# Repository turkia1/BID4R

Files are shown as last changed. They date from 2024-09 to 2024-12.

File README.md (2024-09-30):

# BID4R

# Welcome to the BID4R Rover Model Senior Project

## Overview
The **BID4R Rover Model** is a project designed to develop an efficient power distribution and wireless charging system for a small swarm robot used in the Biologically Inspired Resilient Systems Test Arena (BIRSTA). The current system uses AA batteries, which only provide about 15 minutes of operational time, limiting the research capabilities of the system.

Our project focuses on upgrading one of the 50 swarm rovers to:
- Use **LiPo batteries** to extend operational time to 60 minutes.
- Implement a **wireless charging station** to eliminate manual recharging.
- **Optimize** the rover's structure and design for improved performance and safety.

This proof-of-concept project serves as the foundation for future upgrades across the entire swarm.

## Key Features
- **Power Distribution System**: Upgrading the current system to a **3000 mAh LiPo battery**.
- **Wireless Charging Protocol**: Implementing a **Qi wireless charging station** to allow for easy, cable-free recharging.
- **Rover Design Enhancements**: Reducing the rover structure from four tiers to three tiers for a simpler and more compact design.
- **3D-Printed Battery Mount**: A custom-designed mount that ensures stability and protection for the battery and charging components.
- **Battery Monitoring Algorithm**: Implementing software to track battery life, temperature, and optimize charging times to extend battery longevity.

## Stakeholders
- **Primary Stakeholders**: Dr. Watson and the Biologically-Inspired Design for Resilience Lab.
- **Secondary Stakeholders**: Research teams working on robotic swarms and engineers interested in sustainable power systems for small-scale robots.

## Project Goals
- Develop and test the power distribution system using LiPo batteries.
- Implement wireless charging on the rover and validate performance.
- Showcase a continuous operation of 60 minutes using wireless charging.

## Out of Scope
- Modifications to the remaining 49 rovers in the swarm.
- Autonomous navigation to charging stations.

## Repository Contents
- **Documentation**: All necessary documents, reports, and designs related to the BID4R rover upgrade.
- **Code**: Source code for battery monitoring, power distribution, and wireless charging protocols.
- **Designs**: 3D models for the battery mount and structural modifications of the rover.

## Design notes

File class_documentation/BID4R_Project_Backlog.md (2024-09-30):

# BID4R Project Backlog

## Sprint 1 (Sep 17 – Sep 26) - Done
**Focus:** Project setup and planning.

### Tasks Completed:
1. **Project Proposal (Team):** Done.
2. **Initial Product Backlog (Team):** Done.
3. **Team and component research strategy set (Team):** Done.

---

## Sprint 2 (Oct 1 – Oct 10)- **In Progress**
**Focus:** Research and component verification.

### Tasks:
1. **Research existing and alternative components (Mohammed):** In Progress  
  Verify if the components chosen (PowerBoost, proximity sensors, etc.) are suitable and if new ones are needed.
2. **Perform calculations (Team):** In Progress    
   Conduct power-flow calculations to check system efficiency.
3. **Design initial 3D charging station structure (Turki):**  In Progress  
   Ensure it aligns with the robot’s dimensions and has room for the cooling mechanism.
4. **Research LiPo battery safety and regulations (Belal):**  In Progress  
   Ensure the LiPo battery is compliant with safety standards and meets project requirements.

---

## Sprint 3 (Oct 15 – Oct 24)- **To Do**
**Focus:** Design finalization and algorithm development.

### Tasks:
1. **Finalize charging station design (Turki):**  To Do  
   Finalize the design of the charging station, ensuring it aligns well with the robot and cooling mechanism.
2. **Write distributed power management algorithm (Mohammed-Belal):**  To Do  
   Ensure the algorithm includes power safety protocols.
3. **Develop wiring diagram (Team):**  To Do  
   Create the wiring diagram for the robot, showing how components will be connected (PowerBoost, batteries, proximity sensors).
4. **Review and approve safety protocol (Team):**  To Do  
   Ensure the safety protocol covers all risks and is ready for testing.
5. **Prepare for component integration (Team):**  To Do  
   Gather all necessary components and start preparing for physical integration into the robot system.

---

## Sprint 4 (Oct 29 – Nov 7)- **To Do**
**Focus:** Component integration and initial testing.

### Tasks:
1. **Integrate PowerBoost, proximity sensors, and batteries (Team):**  To Do  
   Wire and physically install the key components (PowerBoost, sensors, batteries).
2. **Install wireless power transmitter and receiver (Team):**  To Do  
   Complete the integration of the wireless charging system.
3. **Test algorithm in a simulated environment (Team):**  To Do  
   Test the power management algorithm on the software side before full system integration.
4. **Test cooling mechanism prototype (Team):**  To Do  
   Ensure the charging station cooling mechanism works effectively.

---

## Sprint 5 (Nov 12 – Nov 21)- **To Do**
**Focus:** Full system testing and optimization.

### Tasks:
1. **Test full power system with wireless charging (Team):**  To Do  
   Run tests on the fully integrated power system to ensure it functions properly.
2. **Iterate on safety protocol (Team):**  To Do  
   Adjust the safety protocol based on test results, especially for overheating or charging errors.
3. **Test proximity sensor performance (Team):**  To Do  
   Ensure that the proximity sensors are working effectively with the robot’s control system.
4. **Implement charging station cooling mechanism (Team):**  To Do  
   Ensure cooling efficiency during the robot’s charging cycles.
5. **Reduce layers in power system design (Team):**  To Do  
   Optimize the design by reducing complexity in the power system if needed.
6. **Prepare and submit presentation poster (Team):** To Do   
   Start drafting the poster for the final project presentation.

---

## Sprint 6 (Nov 26 – Dec 5)- **To Do**
**Focus:** Final preparations and presentations.

### Tasks:
1. **Record 3-minute project video (Team):**  To Do  
   Create the video explaining the project and demonstrating the robot in action.
2. **Prepare final presentation (Team):**  To Do  
   Finalize the project presentation, including results, test data, and the overall project narrative.
3. **Test robot under real conditions (Team):**  To Do  
   Conduct a final test of the robot in an environment similar to its intended use case.
4. **Finalize all documentation (Team):**  To Do  
   Make sure that wiring diagrams, safety protocols, and testing data are fully documented and ready for submission.

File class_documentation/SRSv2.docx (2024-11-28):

BID4R

System Requirements Specification

Version <1.1>

27/11/2024

# Document Control

## Distribution List

The following list of people will receive a copy of this document every time a new version of this document becomes available:

Teaching assistants:

Luke Newcomb

Customer(s):

Dr.Bryan Watson

Project team members:

Turki Alturki

Belal Abed

Mohammed Alasmari

## Change Summary

The following table details changes made between versions of this document:

Version | Date | Modifier | Description
1.0 | 23/10/2024 | Turki Alturki | Introduction
1.0 | 24/10/2024 | Mohammed Alasmari | General Discerption
1.0 | 24/10/2024 | Belal Abed | External Interface Requirements
1.0 | 25/10/2024 | Turki Alturki | Behavioral Requirements
1.0 | 25/10/2024 | Mohammed Alasmari | Non- Behavioral Requirements
1.0 | 25/10/2024 | Belal Abed | Other Requirements
1.0 | 27/10/2024 | Belal, Mohammed | Analysis Models
1.0 | 29/10/2024 | Turki | To be determined list
1.1 | 27/11/2024 | Turki, Belal and Mohammed | Revision of requirements based on feedback

Table of Contents

# 1. Introduction

## Purpose and Scope

The purpose of this System Requirements Specification (SRS) is to detail the system requirements for the BID4R Project, a biologically-inspired resilient rover system designed to replace AA battery-powered rovers with LiPo battery-powered rovers. The BID4R Project focuses on upgrading power systems for autonomous robots in the Biologically-Inspired Resilient Systems Test Arena (BIRSTA), with the goal of extending operational time and introducing wireless charging functionality. Identified through needs analysis, the customer’s primary issue is the limited battery life of current rovers, which necessitates frequent manual recharging and maintenance. This new system addresses that challenge by incorporating LiPo batteries and a wireless Qi charging mechanism, enabling longer operational time and autonomous charging upon manual placement in the station. Applied to a swarm of 50 rovers, the system enhances power management, wireless charging, and control capabilities. Its top-level benefits include improved autonomy, reduced maintenance, and more efficient energy management, achieved through safe battery use managed by a Battery Management System (BMS) and optimized operational efficiency with wireless charging.

## Intended Audience and Reading Suggestions

This document is intended for several types of readers involved in or evaluating the BID4R project:

- Developers responsible for designing and implementing the system.
- Project Manager who oversees project milestones and ensures that all requirements are met.
- Customer who will review the system requirements to assess alignment with project goals.
- Professors and Teaching Assistants who will evaluate and grade the document for technical accuracy and completeness.

### Reading suggestions

- Non-Technical Readers: Focus on the Introduction and General Description sections for a high-level understanding of the project and its goals.
- Developers: Concentrate on the External Interface Requirements and Behavioral Requirements sections for design and implementation guidance.
- Project Manager: Review all sections to ensure milestones are addressed and requirements are met.
- Professors and Teaching Assistants: Examine all sections to evaluate the document's technical accuracy, organization, and alignment with project requirements.

## Document Conventions

The following standards and typographical conventions are followed in this SRS to ensure consistency and clarity:

- Hierarchical Structure: All headings follow a hierarchical numbering system, with primary headings numbered as 1, 2, 3, etc., and subheadings as 1.1, 1.2, etc., to indicate document structure.
- Fonts and Styles: Body text is in 12-point Times New Roman, while headings are bolded for clear visual separation. Terms needing emphasis are italicized, while system names and technical terms are capitalized for clarity.
- Requirement Numbering: Each requirement is labeled with a unique identifier, such as " [Req 1]”," " [Req 2]," and so on, for easy reference and traceability.
- Priority Inheritance: Priorities for higher-level requirements are inherited by lower-level requirements unless otherwise specified.

These conventions are intended to enhance readability and provide a structured approach to navigating the document.

## Project References

This section lists key references and deliverables produced to date, which provide insight into system design choices, power calculations, and safety mechanisms related to LiPo battery management. All documents are accessible on the project’s GitHub repository, with version control details included for reference.

- Project Proposal, BID4R
  - Authors: BID4R Team
  - Date: 2024
  - Description: An overview of project goals, requirements, and initial design considerations for the BID4R system.
  - GitHub Location: https://github.com/turkia1/BID4R/blob/fc681bb0e57aabb8ba3e043f27d15630247c62c0/project_proposal/Project%20Proposal%20.pdf
- Components Analysis and Suitability for BID4R Project
  - Author: Mohammed Alasmari
  - Date: October 2024
  - Description: Analysis of key components required for the BID4R system, including suitability evaluations and performance considerations.
  - GitHub Location: https://github.com/turkia1/BID4R/blob/fc681bb0e57aabb8ba3e043f27d15630247c62c0/Sprint2/Components%20Analysis%20and%20Suitability%20for%20BID4R%20Project.pdf
- LiPo Battery Safety and Wireless Charging Mechanism: A Comprehensive Guide
  - Author: Belal Abed
  - Date: October 2024
  - Description: Guidelines on LiPo battery safety standards and implementation of Qi wireless charging, focusing on safety protocols and regulatory compliance.
  - GitHub Location: https://github.com/turkia1/BID4R/blob/fc681bb0e57aabb8ba3e043f27d15630247c62c0/Sprint2/LiPo_regulation.PDF
- Final Power Calculations for BID4R
  - Authors: Mohammed Alasmari and Belal Abed
  - Date: October 2024
  - Description: Comprehensive power calculations for the BID4R system under various operating conditions, including normal and stall power requirements.
  - GitHub Location: https://github.com/turkia1/BID4R/blob/fc681bb0e57aabb8ba3e043f27d15630247c62c0/Sprint2/FinalCalculation.Component.pdf
- Wiring Documentation for BID4R
  - Author: Turki Alturki
  - Date: October 2024
  - Description: Detailed wiring documentation outlining component connections, safety protocols, and wiring schematics for BID4R.
  - GitHub Location: https://github.com/turkia1/BID4R/tree/fc681bb0e57aabb8ba3e043f27d15630247c62c0/Sprint3/Wiring
- Charging Station Documentation
  - Author: Turki Alturki
  - Date: October 2024
  - Description: Technical documentation on the design and operation of the wireless Qi charging station, including alignment and power specifications.
  - GitHub Location: https://github.com/turkia1/BID4R/tree/fc681bb0e57aabb8ba3e043f27d15630247c62c0/Sprint2/Charging_Station

## Definitions, Acronyms, and Abbreviations

This section provides a glossary of terms and acronyms used in this document.

### Definitions

Term | Definition
LiPo Battery | A type of rechargeable battery widely used for high-energy density applications.
BMS | Battery Management System, responsible for protecting batteries from overcharge, over-discharge, and short circuits.
Qi Charging | A wireless power transfer standard used for charging the rover’s battery.
Arduino Nano | The microcontroller used to manage power and motor control in the system.

### Acronyms

Term | Definition
BMS | Battery Management System
SRS | System Requirements Specification
Qi | Wireless charging technology
BID4R | Biologically-Inspired Design for Resilience

### Abbreviations

Term | Definition
e.g. | For example
V | Voltage
A | Amperes
W | Watts

# 2. General Description

## Product Perspective

The BID4R Project is a subsystem designed to improve the autonomy and operational efficiency of rovers used in the Biologically-Inspired Resilient Systems Test Arena (BIRSTA). Currently, BIRSTA's rovers rely on AA batteries, which require frequent manual replacements and limit runtime. This project aims to replace the AA batteries with a LiPo battery and integrate a Qi wireless charging system to allow convenient, operator-assisted charging.

This power upgrade enhances BIRSTA’s ability to conduct continuous testing by reducing downtime due to manual battery changes. The BID4R system consists of four main components:

1. LiPo Battery: Replaces the original AA battery pack, providing higher capacity and improved power efficiency.
2. Qi Wireless Charging Station: Enables contactless charging of the rover by an operator who manually aligns the rover on the charging pad.
3. Battery Management System (BMS): Monitors battery voltage, prevents overcharging and over-discharging, and ensures safe operation.
4. Arduino Nano-based Control System: Manages communication between the Qi charging module, LED indicators, and the BMS, providing power status updates to the operator.

Figure 1: BID4R Concept of operation illustrates the key components and connections within the system for power, charging, and control.

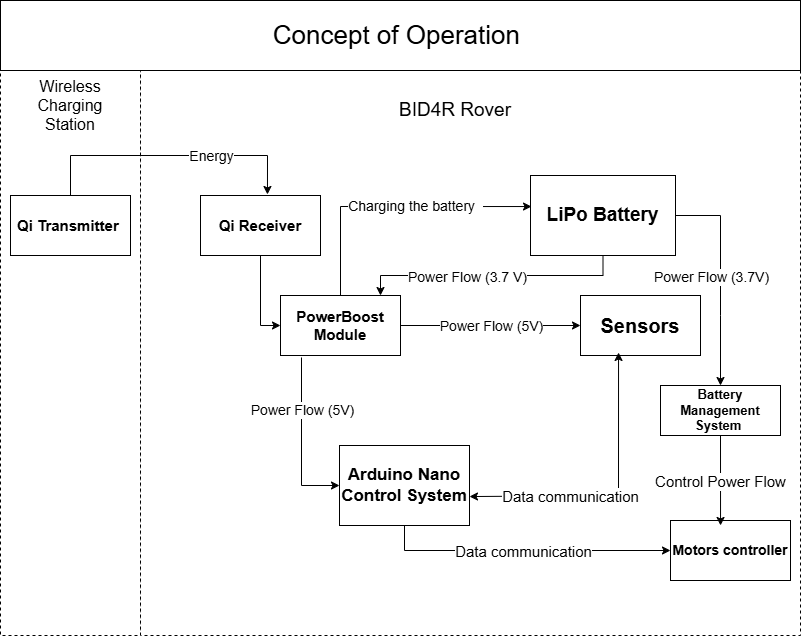
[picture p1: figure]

## Product Features

The BID4R system introduces specific power management features designed to improve battery efficiency, provide safe charging, and enable operational monitoring by the user. Key features include:

- Power Management:
  - Operator-Assisted Wireless Charging: The system uses Qi wireless technology to enable contactless charging. When the battery is low, an operator places the rover on the charging station, which detects the connection and initiates charging.
  - Battery Management System (BMS): The BMS monitors the LiPo battery, preventing overcharging and over-discharging, which ensures safe battery operation and prolongs battery life.
  - Power Monitoring: Real-time monitoring of battery voltage and temperature, displayed via an LED indicator, helps operators assess the rover’s power status.
- System Control:
  - LED Indicators for Battery Status: An LED indicator provides real-time feedback on the battery’s charge status, showing low, charging, and fully charged states, allowing operators to manage charging effectively.
  - Arduino-Controlled Charging Initiation: The system includes an Arduino Nano microcontroller to handle battery status data, control the LED indicator, and communicate with the charging station.

## User Classes and Characteristics

This system is used by the following user groups:

- Primary User: BIRSTA Staff (System Operators)
  - Function: The primary users are BIRSTA engineers or technical staff who operate and monitor the BID4R rover within the test arena.
  - Use: BIRSTA staff will place the rover on the charging station when the LED indicates low battery, monitor the LED status during charging, and remove the rover once fully charged.
  - Privileges: Full access to physical interactions with the system but no access to configurations or code adjustments.
  - Technical Expertise: Moderate; users need to understand LED indicators and basic power system handling but are not required to configure or troubleshoot the system beyond aligning the rover on the charging station.
- Secondary Users: Students (Project Developers)
  - Function: Students are responsible for developing, testing, and integrating the wireless charging station and LiPo battery upgrade, ensuring that the system operates safely and meets performance standards.
  - Use: Configure and test the Qi wireless charging system and BMS functionality.
  - Privileges: Full access to system setup and configuration but restricted to power management components.
  - Technical Expertise: Moderate-to-high; students are expected to understand LiPo battery management, wireless charging setup, and basic troubleshooting for integration.

### Actors

- BIRSTA Staff (Operators): Responsible for the day-to-day operation of the BID4R system, primarily focused on managing power levels through charging.
  - Responsibilities:
    - Observe LED indicators to monitor battery levels.
    - Place the rover on the charging station when necessary and remove it once fully charged.
- Students (Project Developers): Responsible for implementing and maintaining the charging system and battery management components.
  - Responsibilities:
    - Configure and test the Qi charging system and LiPo battery setup.
    - Monitor system safety compliance and handle troubleshooting as needed.

### Use Cases

- Figure 2: UC1: Operator-Assisted Charging

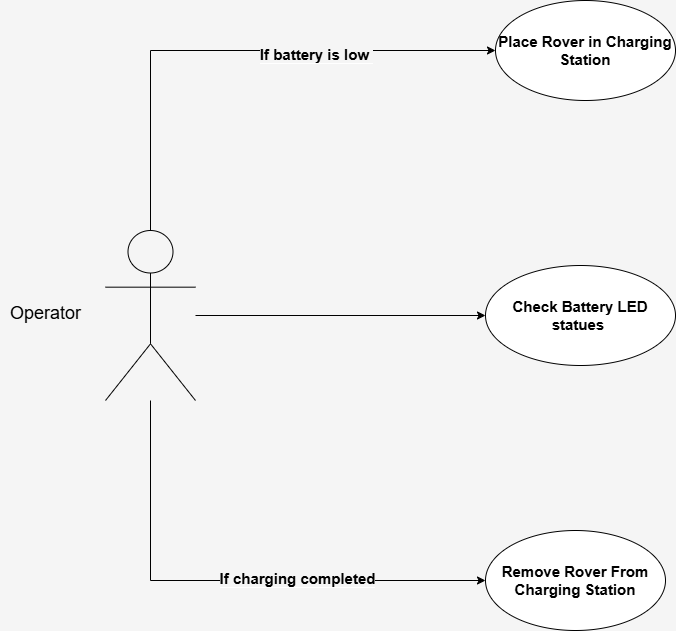
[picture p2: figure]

  - Actors: BIRSTA Staff (Operators)
  - Description: When the battery is low, the operator places the rover on the charging station, where the system automatically initiates charging.
  - Precondition: The battery level is low.
  - Postcondition: Charging begins, and the system logs the session.
  - Alternative Scenario: If alignment is incorrect, the LED remains in a low-battery state, signaling the need for realignment.
- Figure 3: UC2: Create Charging Station System

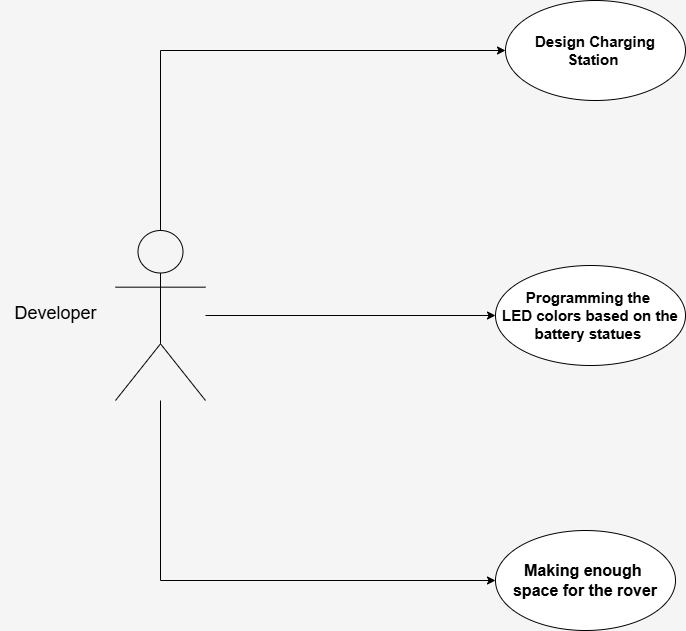
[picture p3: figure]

  - Actors: Students (Project Developers)
  - Description: The Developer designs a reliable charging station, programs LED indicators for battery status (Red, Yellow, Green, and Solid Blue), and ensures sufficient space for easy docking, removal, and maintenance of the rover.
  - Precondition: All required components (charging station, LED indicators, and rover chassis) are available, and the design specifications are approved.
  - Postcondition: The charging station is fully functional, LED indicators display the correct battery status, and the rover can dock, charge, and be removed easily for operation and maintenance.

### Scenarios

This section presents scenarios for each use case described above.

Scenario 1: Initiating Charging

- Description: When the rover’s LiPo battery is low, students monitor the LED indicator and manually place the rover on the Qi wireless charging station to initiate charging.
- Actors: Operators
- Precondition: The rover’s battery level is low, as indicated by the LED.
- Trigger: The operator observes the LED indicator showing a low battery level.
- Steps:
  1. The operator checks the LED indicator to confirm the low battery.
  2. The operator ensures the charging station is clear and ready for alignment.
  3. The operator carefully places the rover on the Qi charging station, aligning it for effective power transfer.
  4. The LED indicator changes to indicate charging, confirming proper alignment.
  5. The operator observes the LED briefly to confirm charging stability.
- Result: The rover is charging, as indicated by the LED status light.
- Alternative Path:
  6. Step 3.1: If the rover is misaligned and charging does not start, the LED remains in its low-battery state. The student repositions the rover until charging initiates.

Scenario 2: Removing the Rover After Full Charge

- Description: Once the rover’s LiPo battery is fully charged, the student observes the LED indicator and removes the rover from the charging station for deployment within BIRSTA.
- Actors: Operators
- Precondition: The rover’s battery is fully charged, indicated by the LED.
- Trigger: The operator observes the LED indicator showing a full charge.
- Steps:
  1. The operator verifies the LED to confirm the full charge status.
  2. The operator approaches the charging station to remove the rover.
  3. The operator carefully lifts the rover off the charging station.
  4. The operator inspects the LED indicator briefly to ensure it remains in the full charge state.
  5. The rover is now ready for BIRSTA deployment.
- Result: The rover is fully charged, removed from the charging station, and available for further use.
- Alternative Path:
  6. Step 3.1: If the LED flashes unexpectedly after removal, the Operator checks the charging station for alignment or functionality issues before proceeding.

## General Constraints

- Code Accessibility: The development team will not have access to the full codebase of the rover, as it is part of an unpublished project and cannot be shared with the team due to confidentiality restrictions. The team will therefore focus on developing code specifically for the battery management system (BMS) algorithm, ensuring independent functionality within the rover’s existing power system.
- Component Selection: To maintain budgetary efficiency, the team will prioritize cost-effective components that meet performance requirements, aiming to reduce overall project costs without sacrificing quality or essential functionality.
- System Modifications: The development team is constrained to avoid modifying the existing rover system to ensure it remains compatible with the customer's current operational use. This ensures the rover’s functionality and user interface remain unchanged for the customer.
- Parts Compatibility: The team will work within the constraints of using components that are already available to the customer whenever possible, ensuring compatibility and minimizing the need for introducing new, unfamiliar parts.

## Operating Environment

- The BID4R system will operate in a controlled laboratory environment within the Biologically-Inspired Resilient Systems Test Arena (BIRSTA) lab. Key environmental requirements include:
- Temperature Range: The system is designed to operate at ambient temperatures between 18°C and 27°C (64°F to 80°F). This range helps prevent temperature-induced issues such as increased viscosity in adhesives and potential component stress, maintaining stability for all electronic parts.
- Humidity: The lab environment maintains a humidity range between 30% and 70%, with a preferred range of 45-60%. These levels reduce the risk of electrostatic discharge (ESD) and prevent moisture damage to sensitive electronic components.
- Hardware Platform: The rovers are managed by an Arduino Nano microcontroller, and the Qi wireless charging station utilizes a PowerBoost 1000C module for reliable energy delivery.
- Software Requirements: The control software operates on the Arduino Nano(C++), handling communications with integrated sensors, motors, and the Battery Management System (BMS) to support system functions.

## User Documentation

The following user documentation will be provided with the BID4R system:

- Charging Station Design Documentation: Detailed design and setup instructions for the Qi wireless charging station, including component specifications and configuration guidelines to ensure proper alignment and functionality.
- Wiring Diagram: A visual guide detailing the connections between all system components, including the battery, sensors, motor drivers, and control modules, offering a reference for accurate assembly and troubleshooting.
- Components and Power Consumption Calculation Documentation: Documentation outlining the system's power requirements and consumption calculations to help users monitor and optimize energy use within safe operating limits.
- LiPo Battery Safety Regulation: Comprehensive guidelines on the safe handling, usage, and maintenance of LiPo batteries, including storage recommendations, charging protocols, and precautions to avoid overcharging or overheating.

All documentation will be provided in PDF format, formatted for clarity and ease of use, and will include annotated diagrams and visual aids where relevant to support user comprehension.

## Assumptions and Dependencies

The following assumptions and dependencies affect the requirements outlined in this SRS:

- Arduino Code Accessibility: It is assumed that the source code for controlling the Arduino Nano 33 IoT will be accessible under supervision to the development team to facilitate integration and testing of the battery management system (BMS).
- Component Provision: The organization will supply all essential components, including the Battery Management System (BMS), Qi chargers, and LiPo batteries. These components are expected to be compatible with the BID4R system and aligned with the project’s cost-efficiency goals.
- Testing Infrastructure: The system will be tested and integrated within the existing BIRSTA robotics infrastructure, assuming compatibility with current robotics protocols, interfaces, and communication systems.
- Environment Control: The system is designed for a controlled lab environment with stable temperature and humidity levels maintained within recommended ranges, supporting the safe and efficient operation of system components.
- Existing Code Functionality: It is assumed that the original rover codebase, aside from the battery management system, operates as intended with no major functional issues.
- System Integrity: It is assumed that all other aspects of the robot’s hardware and software are functioning correctly, and any issues encountered during development are limited to the scope of the team’s work (upgrading the AA battery to LiPo battery).

# 3. External Interface Requirements

## User Interfaces

- [Req 1] The system shall indicate system battery status through an RGB LED.

## Hardware Interfaces

- [Req 2] The motor driver shall be connected to the Arduino for PWM control of motor speed and direction.
- [Req 3] The system shall use an Arduino Nano microcontroller for processing and control.
- [Req 4] The proximity sensor shall be calibrated after installation to ensure accurate readings and proper communication with the Arduino.
- [Req 5] The Pixy2 shall be calibrated after installation to ensure accurate readings and proper communication with the Arduino.
- [Req 6] The system shall include one temperature sensor, positioned near the LiPo battery, to monitor its temperature during charging.
- [Req 7] The PowerBoost 1000C shall provide power for the Pixy2 camera, ensuring it operates within the combined system power limit of 1A.
- [Req 8] The PowerBoost 1000C shall provide power for the VCNL4010 proximity sensor, ensuring it operates within the combined system power limit of 1A.
- [Req 9] The PowerBoost 1000C shall provide power for the APA106 LEDs, ensuring they operate within the combined system power limit of 1A.
- [Req 10] The PowerBoost 1000C shall provide power for the Arduino Nano 33 IoT, ensuring it operates within the combined system power limit of 1A.
- [Req 11] The PowerBoost 1000C shall provide power for any additional 5V components, ensuring the total system power consumption does not exceed 1A.
- [Req 12] The PowerBoost 1000C shall receive 3.7V input from the LiPo battery and provide a stable 5V output for connected components.
- [Req 13] The motor shall be directly connected to the battery through a BMS for protection.
- [Req 14] The BMS protection module shall be installed between the LiPo battery and the load to manage safe charging and discharging.

## Software Interfaces

- [Req 15] All components shall be compatible with Arduino programming standards.
- [Req 16] The software shall monitor battery health, alerting on issues such as temperature or swelling.
- [Req 17] Software logic shall control charging based on feedback from the battery sensors.
- [Req 18] Software logic shall monitor feedback from the battery sensors and control the motors, ensuring they stop operation if dangerous conditions are detected.

# 4. Behavioral Requirements

## Modes

[Req 19] The system shall provide LED indicators for charging status, showing states such as charging, full, and standby.

[Req 20] The system shall have two modes

- Charging Mode
- [Req 21] The system shall flash the indicator LED green when the battery is above 60% charge and the system is in charging mode.
- [Req 22] The system shall flash the indicator LED yellow when the battery is between 30% and 60% charge and the system is in charging mode.
- [Req 23] The system shall flash the indicator LED red when the battery is below 30% charge and the system is in charging mode.
- [Req 24] The system shall display a solid blue indicator LED when the battery is above 95% to indicate “Charging Complete” in charging mode.
- Operation Mode
- [Req 25] The system shall display a green indicator LED when the battery is above 60% charge and the system is in operation mode.
- [Req 26] The system shall display a yellow indicator LED when the battery is between 30% and 60% charge and the system is in operation mode.
- [Req 27] The system shall display a red indicator LED when the battery is below 30% charge and the system is in operation mode.

## Related Real-world Objects

- [Req 28] The system shall maintain the battery temperature below 45°C during normal operation.
- [Req 29] The system shall alert the operator by turning the LED indicator orange if the battery temperature exceeds 45°C.
- [Req 30] The system shall monitor the battery temperature in real-time to ensure it remains within safe operating limits (below 45°C).
- [Req 31] The Arduino shall automatically cut power if the battery temperature reaches unsafe levels.
- [Req 32] The charging station shall allow manual activation by the operator of the cooling fan.
- [Req 33] The charging station shall allow manual deactivation by the operator of the cooling fan.

## Stimulus

- [Req 34] LED indicators shall change states according to battery level.
- [Req 35] Wireless charging shall commence automatically once the robot is aligned with the transmitter.
- [Req 36] The Arduino shall automatically cut power if the battery temperature reaches unsafe levels exceeding 45°C.
- [Req 37] The system shall resume charging automatically when temperature falls below 35°C if previously halted due to overheating.
- [Req 38] The system shall disable motors while charging.
- [Req 39] The system shall disable the Pixy2 camera while charging.
- [Req 40] The system shall disable the proximity sensor while charging.

## Functional

- [Req 41] The system shall stop charging when the battery voltage reaches or exceeds 4.2V automatically through PowerBoost 1000C.
- [Req 42] The system shall permit charging only when the battery voltage is below 4.2V.
- [Req 43] The system shall define a thermal cutoff as a battery temperature greater than 45°C.
- [Req 44] The system shall indicate a thermal cutoff by flashing the RGB LED orange.
- [Req 45] The system shall define non-essential components as the Pixy2 camera, motor controller, and proximity sensor.
- [Req 46] The system shall automatically stop the Pixy2 camera when the battery voltage is 3.3V or below.
- [Req 47] The system shall automatically stop the motor controller when the battery voltage is 3.3V or below.
- [Req 48] The system shall automatically stop the proximity sensor when the battery voltage is 3.3V or below.

# 5. Non-behavioral Requirements

## Performance Requirements

- [Req 49] The system shall support wireless charging via a Qi-compatible charging station.
- [Req 50] The rover shall use a LiPo battery for primary power.
- [Req 51] The BMS shall prevent battery overcharge.
- [Req 52] The BMS shall prevent battery over-discharge.
- [Req 53] Under normal operation, the LiPo battery shall provide a minimum runtime of one hour.
- [Req 54] The Qi transmitter shall maintain a stable position on the charging station base to ensure consistent power transfer.
- [Req 55] The charging station shall ensure efficient power transfer throughout the charging process without interruptions.
- [Req 56] The system shall consume no more than 13.05W at peak usage.
- [Req 57] The Qi receiver and transmitter shall be aligned within ±3 mm to optimize charging efficiency and prevent power loss.
- [Req 58] The charging station shall incorporate a rising edge and block system to ensure precise docking alignment.
- [Req 59] The LiPo battery shall have a capacity of at least 3000 mAh.
- [Req 60] The motors shall draw 2.22W during normal operation (3.7V at 300mA per motor).
- [Req 61] The motors shall draw 11.1W under stall conditions (3.7V at 1.5A per motor).
- [Req 62] Under normal operating conditions, the LiPo battery shall provide a runtime of approximately 2.66 hours.
- [Req 63] Under stall conditions, the LiPo battery shall provide a runtime of approximately 51 minutes.
- [Req 64] The total power consumption during normal operation, including motors and PowerBoost-powered components, shall not exceed 4.17W.
- [Req 65] The total power consumption during motor stall conditions shall not exceed 13.05W.
- [Req 66] The Qi wireless charging transmitter shall provide 5W output to the Qi receiver with an efficiency of 80%.
- [Req 67] The Qi charging system shall fully recharge the LiPo battery within approximately 2.78 hours.
- [Req 68] The BMS shall not consume significant power (2.22W) during normal operation, functioning as a passive protection component.
- [Req 69] The system shall be able to provide sufficient power for different components on the robot.

## Safety Requirements

- [Req 70] The system shall monitor battery temperature using a DS18B20 temperature sensor.
- [Req 71] All wiring shall be neatly organized and securely fastened to prevent interference with the robot's movement and docking.
- [Req 72] The BMS shall protect the health of the battery by preventing over-discharge.
- [Req 73] The thermal cutoff shall disconnect charging if the temperature exceeds 113°F (45°C).
- [Req 74] All electrical connections shall be insulated to prevent accidental short circuits or interference.
- [Req 75] The system shall include a BMS for parts connected directly to the battery.

## Qualitative Requirements

### Security

- [Req 76] Access to the code for the battery management system (BMS) shall be restricted to authorized team members only, ensuring secure control over system operations and modifications.

### Maintainability

- [Req 77] The BMS code shall be modular to allow for future updates and improvements without affecting unrelated system components, supporting efficient system maintenance and upgrades

## Design and Implementation Constraints

- [Req 78] The robot chassis shall securely mount the Qi receiver, providing enough space and accessibility for wiring and maintenance.
- [Req 79] The robot chassis shall securely mount all components, providing enough space and accessibility for wiring and maintenance.
- [Req 80] The Arduino Nano 33 IoT shall be positioned to allow easy access to all sensor and power connections
- [Req 81] The PowerBoost 1000C shall be positioned to allow airflow for cooling, ensuring stable operation under continuous load.
- [Req 82] The proximity sensor shall be placed at the front of the robot for optimal obstacle detection.
- [Req 83] The APA106 LEDs shall be positioned to remain visible to the operator, providing clear feedback on system status.
- [Req 84] The Qi receiver shall be positioned on the bottom surface of the robot for direct alignment with the transmitter on the charging station.
- [Req 85] Wires shall not interfere with the robot during docking.
- [Req 86] The LiPo battery shall be securely housed to prevent movement, impact, or damage during operation.
- [Req 87] All components shall be fastened securely to avoid damage or disconnection from vibrations or sudden movements.
- [Req 88] The charging station shall be designed for easy assembly and disassembly to facilitate maintenance.
- [Req 89] The design shall accommodate the BID4R robot configuration, which includes two wheels and a middle stabilizer.
- [Req 90] The Qi transmitter shall be positioned at the front of the charging station to align with the BID4R robot’s docking requirements.
- [Req 91] The station shall include a cooling fan.
- [Req 92] The charging station shall include an adjustable fan positioned above the robot to regulate temperature during charging.

# 6. Other Requirements

## User Documentation

- [Req 93] Instructions for proper wire routing to avoid docking interference shall be included in the user manual.
- [Req 94] The documentation shall provide instructions on interpreting LED colors for different battery charge levels.
- [Req 95] The documentation shall specify the LED flashing pattern to indicate thermal cutoff during overheating.

# 7. Analysis Models

## State Model Figure 4: State Model

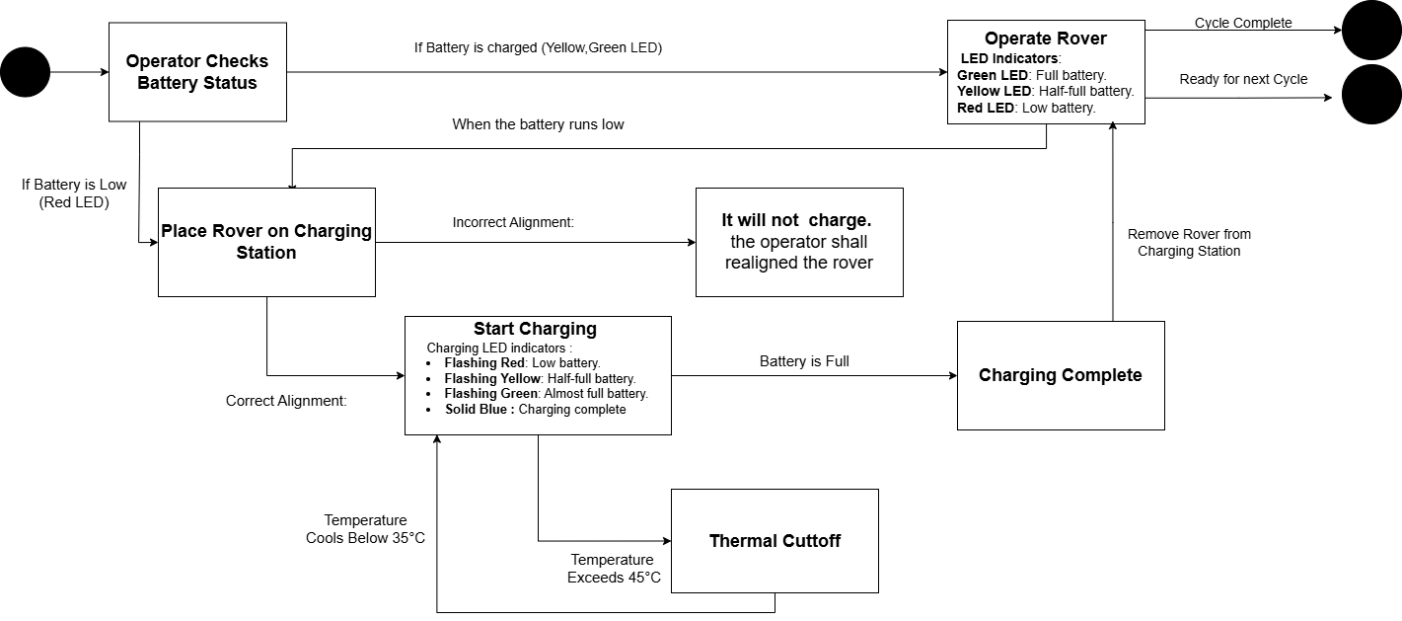
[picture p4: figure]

- State Model Start: The state model begins when the operator checks the battery status of the rover. This is the initial step in the operational cycle of the rover, which determines whether the battery needs charging or if the rover can proceed to operate.
- State Model End: The state model ends when the rover completes its operation cycle and is ready for the next cycle. This includes fully charging the battery (if needed), ensuring thermal safety, and preparing the rover for its next operational task.

# 8. To Be Determined List

- [TBD-1] Confirmation of the controlled lab environment’s specific temperature and humidity range requirements to support optimal system operation.
- [TBD-2] Finalization of authorized personnel roles for accessing and modifying the battery management system (BMS) code.
- [TBD-3] Validation of testing infrastructure compatibility with current BID4R robotics protocols and communication standards.

BID4R System Requirements Specification

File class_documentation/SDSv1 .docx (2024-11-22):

BID4R

System Design Document

Version <1.0>

11/21/2024

# Document Control

## Distribution List

The following list of people will receive a copy of this document every time a new version of this document becomes available:

Teaching assistants:

Luke Newcomb

Customer(s):

Dr. Bryan Watson

Project team members:

Turki Alturki

Mohammed Alasmari

Belal Abed

Change Summary

The following table details changes made between versions of this document:

Version | Date | Modifier | Description
1.0 | 10/30/2024 | Belal | Initial creation- Introduction
1.0 | 11/2/2024 | Mohammed | System Architecture
1.0 | 11/3/2024 | Turki | System Architecture- Diagrams
1.0 | 11/4/2024 | Mohammed | Human - Machine interface
1.0 | 11/6/2024 | Turki | Detailed Design- Hardware
1.0 | 11/8/2024 | Mohammed | Detailed Design- Software
1.0 | 11/9/2024 | Belal | Detailed Design- Internal Communication
1.0 | 11/11/2024 | Belal | External Interface – Hardware
1.0 | 11/16/2024 | Turki | External Interface – Software
1.0 | 11/19/2024 | Turki | Revise the Detailed Design Hardware
1.0 | 11/20/2024 | Turki | Revise the Internal communication
1.0 | 11/21/2024 | Mohammed, Belal, Turki | Final revision

Table of Contents

# 1. Introduction

## 1.1. Purpose and Scope

The purpose of this System Design Specification (SDS) is to detail the technical requirements and design for the BID4R project. The project involves upgrading an existing robot by replacing AA batteries with a LiPo battery and integrating a Qi-compatible wireless charging system. The system aims to extend operational runtime while ensuring safety through battery management and thermal monitoring.

## 1.2. Project Executive Summary

The BID4R project focuses on improving robot functionality by implementing a more efficient power system. This includes transitioning to a LiPo battery, integrating a Qi wireless charging solution, and enhancing safety with thermal and battery monitoring. These upgrades will reduce downtime, improve usability, and enable future enhancements like autonomous docking.

### System Overview

The BID4R system is a power management solution for a mobile robot, designed to extend its operational time and reduce the need for manual recharging through wireless charging. This system comprises two main components: a Qi-compatible wireless charging station and an upgraded power system within the robot, which includes a LiPo battery and a Battery Management System (BMS).

The robot, initially powered by AA batteries, has been modified to incorporate a LiPo battery, which provides a longer operational time per charge. The wireless charging station enables the robot to recharge its battery without the need for physical connection ports. The charging process is initiated automatically when the robot is manually placed on the charging station by an operator. An LED indicator on the robot provides real-time feedback to show the current battery status, signaling when it is fully charged or in need of recharging.

To ensure safety during charging, the system includes a thermal management feature that prevents overheating. The overall system design is straightforward and focused on efficient power integration rather than advanced autonomous functions. In the future, additional navigation features could be added to allow the robot to automatically dock onto the charging station, further enhancing its autonomy.

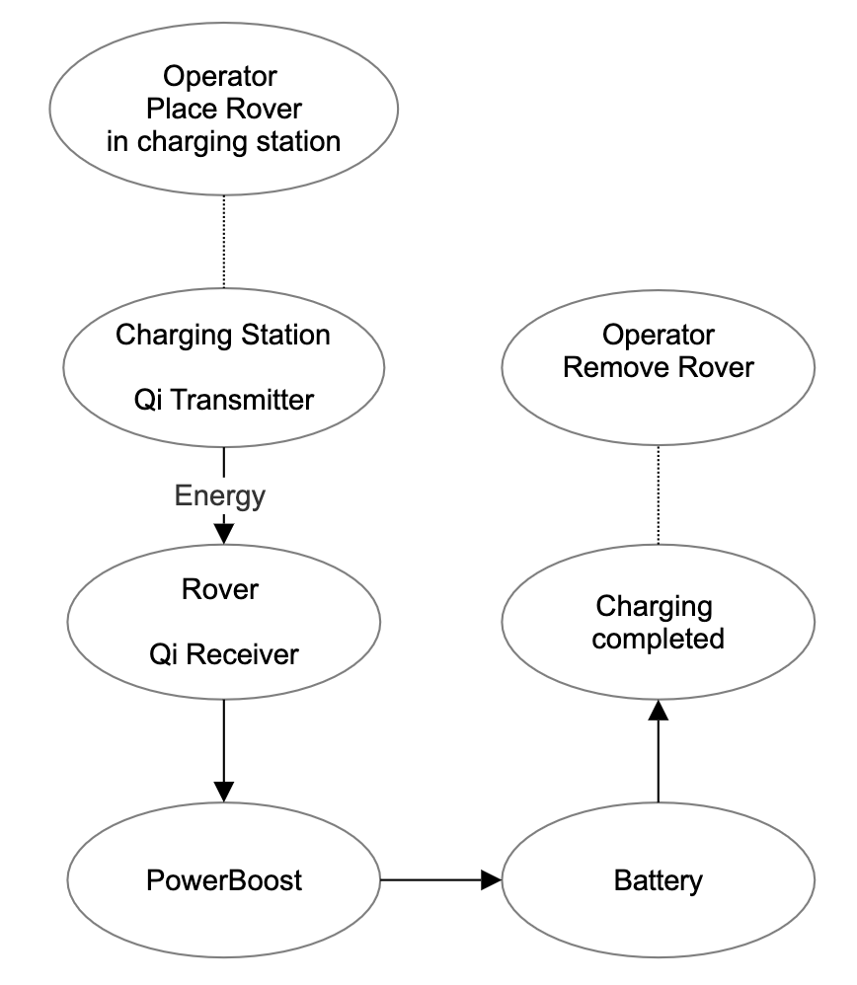
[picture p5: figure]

Figure 1. High-Level Charging Process Flow

### Design Constraints

The BID4R system design is subject to several constraints that influence its hardware, software, and operational setup. These constraints include:

1. Limited System Autonomy: The system relies on manual docking for charging as autonomous navigation is outside the current scope. This requires the operator to manually align and place the rover on the charging station. Future updates could address this limitation by integrating sensors and navigation algorithms for autonomous docking.
2. Power Source Limitations: The system uses a 3.7V, 3000mAh LiPo battery, which provides extended usage but introduces charging and discharging constraints. A robust Battery Management System (BMS) is required to monitor and protect the battery from overcharging or over-discharging, ensuring safe and efficient operation.
3. Qi Wireless Charging Constraints: The Qi charging setup includes a transmitter capable of delivering up to 1000mA; however, the receiver is limited to 500mA. This results in extended charging times, which may not be ideal for high-demand applications. Future upgrades to the Qi receiver could address this bottleneck.
4. Environmental Restrictions: The BID4R system is optimized for use in controlled indoor environments with stable temperature and humidity. It is not designed for rugged conditions such as high dust levels, extreme temperatures, or exposure to moisture. Modifications would be required for outdoor or industrial applications.
5. Software and Hardware Requirements: The system is controlled by an Arduino Nano IoT, with code running on limited memory and processing power. The system’s software is optimized for this low-power environment, meaning complex tasks or additional processes could exceed the capabilities of the microcontroller. The system does not require an external operating system, network connection, or high RAM capacity due to the limited computational demands of the task.

Assumptions:

- The operator will be present to manually place the rover on the charging station.
- The operator will monitor the battery levels through the LED status indicators to determine when the rover requires charging or when the battery is fully charged.
- The components used are compatible with Qi wireless charging standards, ensuring efficient energy transfer between the charger and the receiver in the rover.
- The environment is free from high levels of dust, humidity, or temperature fluctuations, as the system is not designed for rugged conditions.

### Future Contingencies

The BID4R project has been designed with specific functionality and constraints; however, several future contingencies could alter the development direction. These contingencies include potential system upgrades, architectural changes, and external dependencies that may arise as the system evolves or new requirements are introduced.

1. Integration of Autonomous Docking: Currently, the system requires an operator to manually place the rover on the charging station. Future developments may add autonomous navigation and docking capabilities to enhance system autonomy. This would involve integrating additional sensors (e.g., LiDAR, ultrasonic) and navigation algorithms. The system architecture may require updates to accommodate these changes, including more advanced processing capabilities.
2. Upgraded Qi Wireless Receiver: The current Qi wireless charging system utilizes a transmitter capable of delivering up to 1000mA; however, the receiver is limited to a maximum current of 500mA. This limitation prolongs the charging time of the system. Future upgrades could involve replacing the Qi receiver with a higher-capacity model capable of matching the transmitter's output. This enhancement would reduce charging time, improve efficiency, and align the receiver's performance with the transmitter's capabilities.
3. Higher Capacity Battery and Charging System: If extended operational time is required beyond the current LiPo battery capacity, a higher capacity battery or a more efficient wireless charging system may be needed. This could involve re-evaluating the Qi wireless standard or increasing the charging power, which may impact thermal management and require additional safety controls.
4. Environmental Adaptation: The current system is intended for indoor environments. If the system is required to function in outdoor or rugged conditions, modifications may be needed to weatherproof the components, enhance the thermal management system, and ensure reliable operation in varying environmental conditions. This adaptation could necessitate using more robust materials, enclosures, and environmental sensors.
5. Compatibility with External Systems: Future versions of BID4R may need to interface with external systems such as fleet management software or centralized monitoring systems for coordinated operation in larger deployments. This would require network connectivity and standardized communication protocols, which could impact the system’s hardware and software requirements.

Workarounds and Alternative Plans:

- For autonomous docking, alternative navigation methods (e.g., manual alignment aids or low-cost beacons) could be considered if advanced sensors are not feasible.
- If a higher-capacity Qi receiver is not available, the current system can continue to operate with the existing 500mA receiver. While this setup results in longer charging times, it ensures that the system remains fully functional and reliable.
- If a higher capacity battery is required but Qi charging power cannot be increased, a dual-battery system could be used to swap batteries periodically for charging.
- To ensure compatibility with external systems, modular software architecture and standardized data formats could be implemented, allowing future integration with minimal changes.

These contingencies are considered as potential future directions that may arise based on user requirements, system performance, and evolving operational needs.

## 1.3. Document Organization

This System Design Document (SDD) is organized to provide a comprehensive view of the BID4R project’s design, including its purpose, architecture, and specific design components. Each section addresses a different aspect of the system to ensure a clear and structured understanding of the project. The document is organized as follows:

- Section 1: Introduction – Provides the purpose, scope, executive summary, overview of the system, design constraints, future contingencies, and references. It establishes the project context and introduces key objectives and assumptions.
- Section 2: System Architecture – Details the high-level hardware and software architecture, describing the main components of the BID4R system and how they interact. This section includes diagrams to illustrate the system’s structure.
- Section 3: Human-Machine Interface – Defines the inputs and outputs relative to the user or operator, detailing how the operator interacts with the system, particularly through the manual docking and LED status indicators.
- Section 4: Detailed Design – Provides a comprehensive breakdown of the hardware and software design, including specifications for each component and detailed design for internal communications.
- Section 5: External Interfaces – Describes the hardware and software interfaces between the BID4R system and any external systems, including the protocols and standards used for these interactions.

Each section is designed to guide the development, integration, and testing of the BID4R project, providing a clear framework for both current and future system requirements. Diagrams and references are included throughout to support the understanding of the design and implementation processes.

## 1.4. Project References

This section lists the key references and resources consulted during the development of the BID4R project. These references provide background information, technical specifications, and industry standards relevant to the design and implementation of the wireless charging and battery integration solution.

1. Arduino Nano IoT Documentation – Technical documentation for the Arduino Nano IoT, including pin configurations, power limitations, and programming guidelines essential for the control system of the BID4R project.

Link: https://github.com/turkia1/BID4R/blob/main/Wiring_documentation/Component_Documentation/ABX00027-datasheet.pdf

2. Adafruit PowerBoost 1000C Documentation – Specifications and usage information for the PowerBoost 1000C module, including voltage conversion and output capabilities that enable efficient energy transfer from the Qi receiver to the LiPo battery.

Link: https://github.com/turkia1/BID4R/blob/main/Wiring_documentation/Component_Documentation/adafruit-powerboost-1000c-load-share-usb-charge-boost.pdf

3. 3D Design and CAD Files for Charging Station – CAD files and design guidelines used to model the physical structure of the wireless charging station, with specific features for alignment and thermal management.

Link:

https://github.com/turkia1/BID4R/tree/main/Charging_Station_Documentation

4. Wiring and Circuit Design References – Fritzing diagrams and wiring guidelines, used to assemble and validate the connectivity of electronic components, ensuring correct voltage levels, ground connections, and data flow between modules.

Link:

https://github.com/turkia1/BID4R/tree/main/Wiring_documentation

5. Project Requirements Document – A prior document detailing the functional and non-functional requirements of the BID4R project, which provided a foundation for the system design and identified specific operator needs.

Link:

https://github.com/turkia1/BID4R/blob/main/class_documentation/SRSv1.docx

6. Components Analysis for BID4R Project – Analysis report on component suitability and performance metrics, including the choice of sensors, LEDs, and connectors necessary for the seamless operation of the BID4R system.

Link:

https://github.com/turkia1/BID4R/blob/main/Sprint2/Components%20Analysis%20and%20Suitability%20for%20BID4R%20Project.pdf

7. LiPo Battery Safety Regulations -A Comprehensive guidelines on LiPo battery safety standards and implementation of

Qi wireless charging, focusing on safety protocols and regulatory compliance.

Link:

https://github.com/turkia1/BID4R/blob/main/Sprint2/LiPo_regulation.PDF

These references serve as foundational resources for understanding the technologies, safety protocols, and design considerations applied in this project. They provide essential information for the development team and stakeholders to understand the scope, constraints, and technical direction of the BID4R project.

## 1.5. Definitions, Acronyms, and Abbreviations

This section provides a glossary of terms, acronyms, and abbreviations used in this document to assist readers in understanding technical terminology specific to the BID4R project.

### Definitions

This section lists terms used in this document and their associated definitions.

Table 1: Definitions

Term | Definition
Battery Management System (BMS) | A system that monitors and manages the charging and discharging of a battery, ensuring safety and efficiency.
Qi Wireless Charging | A standard for wireless energy transfer using inductive charging over distances of up to 4 cm.
Thermal Management | The process of controlling the temperature of components to ensure safe operating conditions.
Manual Docking | The process of physically placing the robot onto the charging station by an operator for charging.
LiPo Battery | A rechargeable lithium polymer battery known for its high energy density and compact size.

### Acronyms

This section lists the acronyms used in this document and their associated definitions.

Table 2: Acronyms

Term | Definition
SDD | System Design Document
BID4R | Battery Integration and Docking for Rover
BMS | Battery Management System
LED | Light Emitting Diode
IoT | Internet of Things

### Abbreviations

This section lists the abbreviations used in this document and their associated definitions.

Table 3: Abbreviations

Term | Definition
e.g. | For example
i.e. | That is
V | Volt
mA | Milliampere

# 2. System Architecture

This section provides an overview of the BID4R system architecture, focusing on the hardware and software components that enable wireless charging and effective battery management. The BID4R system comprises two primary components: a wireless charging station and a rover equipped with a LiPo battery, Battery Management System (BMS), and status indicators. This section will describe the organization of the system, its components, and their roles in achieving the project objectives.

## 2.1. System Hardware Architecture

The BID4R system’s hardware architecture consists of two main components: Charging Station Components and Rover Components. Together, these components enable seamless wireless charging through inductive coupling based on the Qi wireless power transfer standard and facilitate efficient power management. Below is a detailed breakdown of each component and its role within the system.

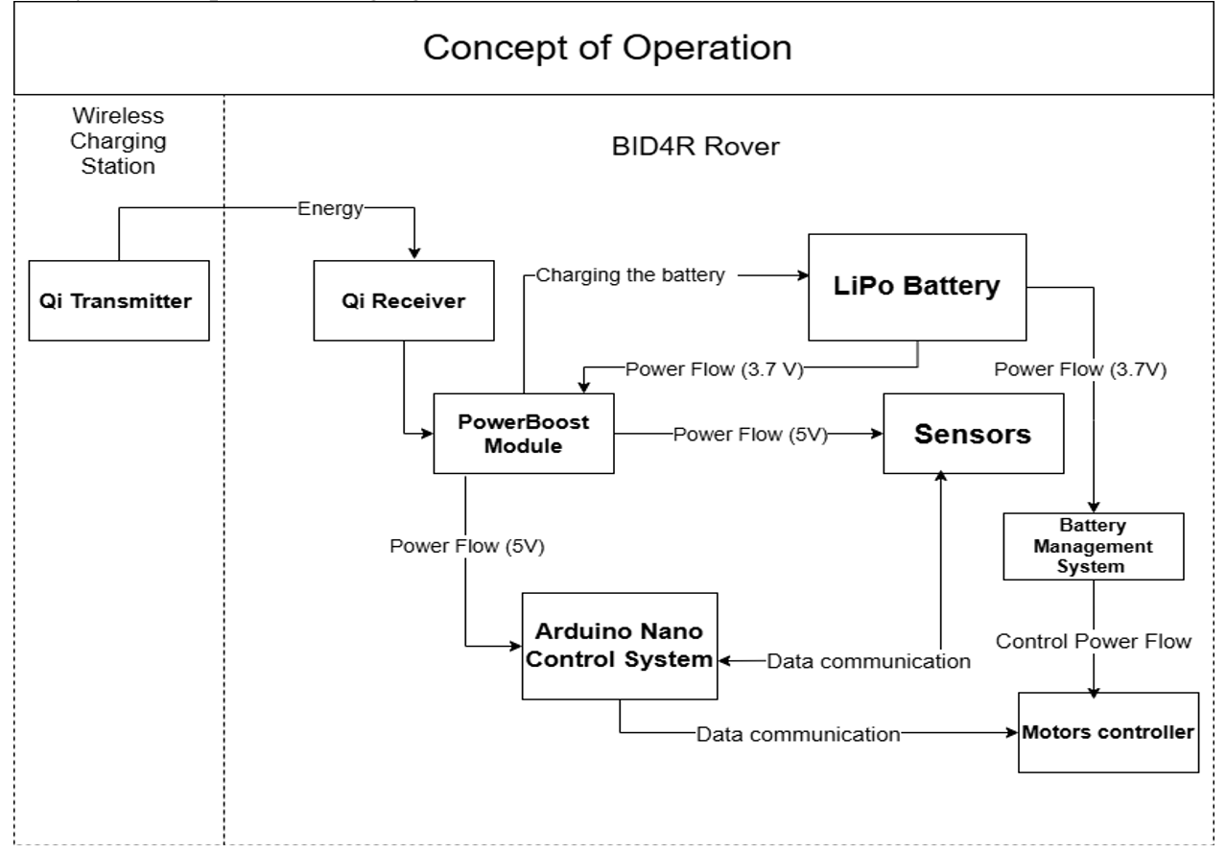
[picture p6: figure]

Figure 2. Hardware Architecture

### Rover Components

1. Qi Receiver Module
  - Function: Receives power wirelessly from the Qi transmitter and forwards it to the PowerBoost module for voltage regulation and distribution.
  - Placement: Positioned on the rover to align precisely with the Qi transmitter on the charging station.
2. PowerBoost 1000C Module
  - Function: The PowerBoost 1000C serves two primary functions:
    - Battery Charging: Converts the Qi receiver’s input to a stable 5V output to charge the LiPo battery.
    - Voltage Boosting and Distribution: Boosts the voltage from the LiPo battery to provide a stable 5V output, distributing power to other components within the system.
  - Safety Features: Includes built-in protection to ensure controlled charging and regulated power output to other components.
3. LiPo Battery (3.7V, 3000mAh)
  - Function: Serves as the primary power source for the rover, providing extended operational time beyond standard AA batteries.
  - Connections: Connects to the PowerBoost module for charging and to the BMS for direct motor power with over-discharge protection.
4. Battery Management System (BMS) Components
  - BMS Module
    - Purpose: Protects the battery by managing power output to the motors and preventing over-discharge.
    - Connections: Interfaces directly with the battery and motors to maintain safe discharge levels during operation.
5. Arduino Nano IoT
  - Function: Central control unit for processing power signals, monitoring sensors, and controlling LED indicators for battery status.
  - Integration: Interacts with the custom BMS, processes sensor data, and coordinates battery status feedback.
6. LED Indicators
  - Purpose: Provides visual feedback on battery charging status, informing the operator of battery levels.
  - Indicators: Display different colors and patterns to indicate states such as charging, full, half-full, and low battery levels.
7. Temperature Sensor (DS18B20)
  - Purpose: Monitors system temperature, specifically during charging cycles, to prevent overheating.
  - Integration: Communicates temperature data to the Arduino Nano IoT for monitoring and thermal management.
8. Motor Controller and DC Motors
  - Purpose: Enables the rover’s movement, powered by the battery.
  - Power Source: Connected to the battery through the pre-existing BMS module to prevent battery over-discharge during usage.

### Charging Station Components

1. Qi Wireless Charging Transmitter
  - Function: Transmits power through inductive coupling to the Qi receiver on the rover, facilitating inductive charging.
  - Placement: Aligned to ensure effective power transfer with the Qi receiver on the rover when docked.
2. Cooling Fan
  - Purpose: Provides airflow over the charging components on the charging station to manage temperature during operation.
  - Operation: The fan is powered separately and is manually controlled by the operator, not connected to the rover’s control system or charging circuitry.

## 2.2. System Software Architecture

The software architecture for the BID4R system is organized into modular components, each responsible for handling specific functions, including power monitoring, charging control, temperature monitoring, and user feedback through LED indicators. The system is programmed using C++ and developed within the Arduino IDE. The modular approach provides scalability and maintainability, allowing each function to operate independently while interacting with shared data elements.

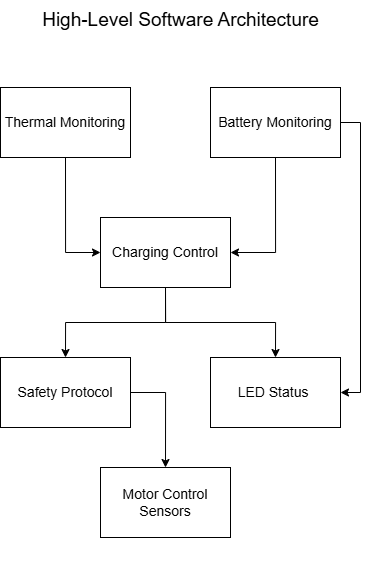
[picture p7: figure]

Figure 3. Software Architecture

### High-Level Software Architecture

The BID4R software is structured around the following key modules:

1. Battery Monitoring Module
  - Description: This module is responsible for continuously monitoring the LiPo battery’s voltage level and sending relevant data to other modules, especially for determining battery charge status.
  - Interactions: Provides battery level data to the Charging Control and LED Status Indicator modules for managing charging operations and displaying real-time feedback.
  - Purpose: Enables real-time power management, ensuring that the system responds appropriately to low, medium, and full battery states.
2. Thermal Monitoring Module
  - Description: This module monitors the system temperature, specifically during the charging process, to prevent overheating. The DS18B20 temperature sensor provides temperature data, which is processed by this module.
  - Interactions: Works in conjunction with the Safety Protocol and Charging Control modules.
  - Purpose: Protects the battery and circuitry by halting charging if the temperature exceeds safe limits.
3. Charging Control Module
  - Description: Controls the charging process based on inputs from the Battery Monitoring and Thermal Monitoring modules. It can start or stop charging based on battery levels and temperature.
  - Interactions: Receives battery status updates from the Battery Monitoring module and temperature data from the Thermal Monitoring module.
  - Purpose: Ensures safe and efficient charging of the battery by managing the Qi charging process according to predefined safety protocols.
4. LED Status Indicator Module
  - Description: This module controls the LED indicators, providing the operator with real-time visual feedback on battery charge levels. Different colors and flashing patterns represent various states such as charging, full charge, or low battery.
  - Interactions: Communicates with the Battery Monitoring and Charging Control modules to display appropriate status.
  - Purpose: Serves as the primary user interface for battery monitoring, alerting the operator about the battery’s current charge level.
5. Motor Control Interface
  - Description: Although not directly involved in the charging process, this module provides an interface to control the rover’s movement. For future developments, it may be integrated with autonomous navigation functions.
  - Interactions: Primarily interfaces with the pre-existing BMS for motor power management.
  - Purpose: Allows for potential expansion of the system to include navigation capabilities.
6. Safety Protocol Module
  - Description: This module handles safety checks, including monitoring for over-temperature or low battery conditions. It coordinates with other modules to implement protective actions when necessary.
  - Interactions: Works closely with the Thermal Monitoring, Battery Monitoring, and Charging Control modules to execute shutdowns or alerts during unsafe conditions.

Purpose: Maintains system stability and safety by enforcing operational limits and initiating appropriate responses to critical conditions

### Development Tools and Environment

- Programming Language: The software is developed in C++, a language well-suited for embedded systems and compatible with the Arduino platform.
- Development Platform: The Arduino IDE is used to code, compile, and upload the software onto the Arduino Nano IoT microcontroller. It provides access to essential libraries for handling sensors, battery monitoring, and LED control.
- Libraries: Standard Arduino libraries are employed for sensor data acquisition, power monitoring, and LED control. These libraries simplify hardware interfacing and enable efficient development.

## 2.3. Internal Communications Architecture

The internal communications architecture of the BID4R system facilitates data exchange between the various hardware components and software modules, allowing seamless communication of battery status, charging conditions, and operational feedback among the modules. This architecture supports effective power management and user feedback while integrating newly added components with existing parts of the rover.

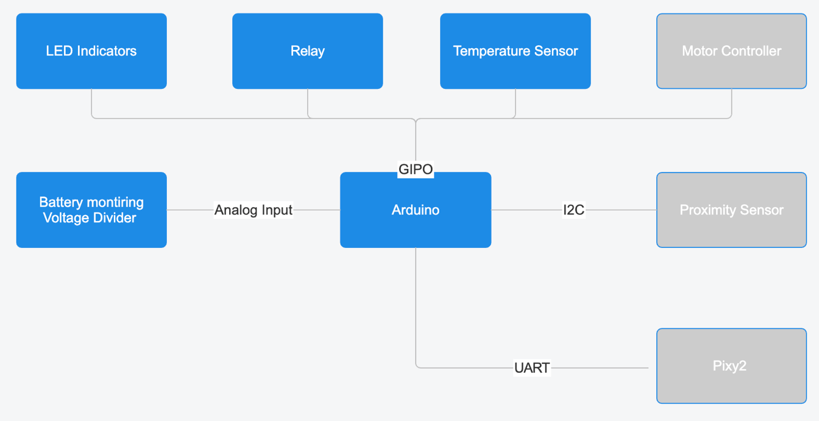
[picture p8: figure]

Figure 4. Internal Communications Diagram.

This diagram shows the data pathways and communication protocols (I2C, UART, GPIO) within the BID4R system. Components in blue are directly involved in the project, while faded components (gray) are pre-existing robot elements impacted but not directly modified in this project.

# 3. Human-Machine Interface

The Human-Machine Interface (HMI) for the BID4R system focuses on the interaction between the operator and the system, specifically through user inputs and outputs. The primary input involves manually placing the rover on the charging station, and the primary outputs are visual indicators that communicate the system’s status, including battery charge level and charging progress.

## 3.1. Inputs

Since the BID4R project’s scope does not include an interactive digital interface, the inputs from the operator are limited to manual actions. These inputs are directly mapped to the system functions described in Section 1.2.1 System Overview.

Input Actions

1. Manual Docking
  - Description: The operator places the rover onto the charging station, ensuring the Qi transmitter and receiver are aligned for charging to begin.
  - Mapping to System Flow: When the rover is correctly positioned, the charging station’s Qi transmitter begins transferring power to the Qi receiver on the rover. This action initiates the charging sequence, which is then managed automatically by the system.
2. Manual Fan Control
  - Description: The user manually activates a cooling fan during charging if overheating is detected.
  - Mapping to System Flow: Although independent from the control system, the fan assists in maintaining safe temperatures. This input is manually controlled without direct communication with the system’s logic.

Access Restrictions and Security Considerations

- The manual docking process requires precise alignment between the rover and the charging station for efficient charging. There are no digital access restrictions for these inputs, as they are purely physical interactions.
- No security protocols are required for input access, as the inputs are simple manual actions without authentication or verification processes.

## 3.2. Outputs

The system’s outputs to the operator are conveyed through LED indicators on the rover. These indicators provide critical feedback on battery levels and charging status, ensuring the operator can monitor the system’s operation in real-time.

LED Indicators as System Outputs

The LED indicators serve as the primary user interface for communicating the system’s status. The LED displays various colors and patterns to represent different battery levels and charging states, enabling the operator to understand the system’s current state at a glance.

The following tables summarize the LED indicators and their meanings:

Table 4: Battery Status Indicator

LED Color/Pattern | Indicator Name | Description | Condition
Red (Solid) | LowBatteryLED | Indicates a low battery level. | Battery level is below safe operational range.
Yellow (Solid) | HalfBatteryLED | Indicates a medium battery level. | Battery is partially charged (approximately 50%).
Green (Solid) | FullBatteryLED | Indicates a nearly full battery level. | Battery is close to full capacity.

Table 5: Charging Status Feedback

LED Color/Pattern | Indicator Name | Description | Condition
Blue (Solid) | ChargingCompleteLED | Indicates the battery is fully charged. | Battery has reached maximum capacity.
Orange (Flashing) | OverheatAlertLED | Indicates an overheat alert. | Temperature exceeds safe operational levels.
Red (Flashing) | ChargingLowBatteryLED | Indicates that charging is in progress with a low battery level. | Battery is below 30% while charging.
Yellow (Flashing) | ChargingMediumBatteryLED | Indicates that charging is in progress with a medium battery level. | Battery is between 30% and 50% while charging.
Green (Flashing) | ChargingHighBatteryLED | Indicates that charging is in progress with a high battery level. | Battery is above 50% while charging.

Purpose and Primary User

The LED indicators serve as the primary user interface for battery monitoring and charging status. They provide instant visual feedback for the operator, enabling them to monitor the battery charge levels and detect any abnormal conditions (such as overheating) during charging.

- Primary User: The operator, who monitors these visual indicators to assess the battery’s charge level and charging status.

Access Restrictions and Security Considerations

  - Access Control: Since the LED indicators are visible to anyone within the vicinity, there are no access restrictions on the outputs. The visual signals are intentionally designed to be observable without specific access permissions.
  - Security Considerations: No additional security considerations are needed, as the LED indicators do not store sensitive data or control system operations beyond visual status display.

# 4. Detailed Design

This section contains the detailed hardware and software design of the BID4R autonomous charging and power management system.

## 4.1. Hardware Detailed Design

This section provides a complete breakdown of the hardware components used in the BID4R system, including their placement, integration, and connections. The design is divided into three subsections: Rover Power and Control System Components, Charging Station Components, and Graphical Representation.

### Rover Components:

### 4.1.1.1 Control System

1. Arduino Nano 33 IoT
  - Placement: Mounted on the upper layer of the robot for centralized access and ease of wiring.
  - Integration: Serves as the main controller, managing all component communication, control, and monitoring.
  - Pin Configuration:

Table 6: Arduino Pins

Pin | Component Connection
D0 (RX) | Pixy2 Camera (RX for serial communication)
D1 (TX) | Pixy2 Camera (TX for serial communication)
D2 | Motor Driver AIN1 (Motor 1 Control)
D3 | Motor Driver AIN2 (Motor 1 Control)
D4 | DS18B20 Temperature Sensor (Data pin)
D5 | Motor Driver BIN1 (Motor 2 Control)
D6 | Motor Driver BIN2 (Motor 2 Control)
D7 | PowerBoost ENABLE through transistor 2A2222A
D8 | APA106 LED (DIN) for controlling the LED strip
D9 | Control Power Relay
D10 | LED for robot feedback
D11 | PowerBoost battery monitoring
D12 | Motors Sleep
D13 | Battery Charging
3.3v | Robot LED + Power relay
A0 | Voltage Divider for battery level monitoring
A4 (SDA) | Proximity Sensor (SDA pin for I2C communication)
A5 (SCL) | Proximity Sensor (SCL pin for I2C communication)

- Power and Ground:

5V: Supplied by PowerBoost to power the Arduino and connected peripherals.

GND: Common ground across the system.

2. DS18B20 Temperature Sensor
  - Placement: Near the battery to monitor temperature.
  - Integration: Monitors temperature to prevent overheating during charging.
  - Connections:
    - VDD: Connected to Arduino’s 3.3V pin.
    - GND: Shared ground.
    - Data Pin: Connected to D2 on Arduino.
3. Pixy2 Camera System
  - Placement: Mounted on the front of the rover for potential vision-based enhancements.
  - Integration: Communicates with Arduino via serial connection.
  - Connections:
    - TX/RX: Connected to Arduino’s D0 (RX) and D1 (TX).
    - 5V Power: Supplied by PowerBoost.
    - GND: Connected to shared ground.
4. Proximity Sensor (Adafruit #466)
  - Placement: Mounted on the front of the rover, near the Pixy
  - Integration: Assists the robot on detecting objects
  - Connections:
    - SDA: Connected to Arduino A4 (I2C data).
    - SCL: Connected to Arduino A5 (I2C clock).
    - VDD: 3.3V from Arduino.
    - GND: Shared ground.
5. Relay
  - Placement: Mounted on the second layer of the robot, adjacent to the motor controller for efficient space utilization and wiring
  - Integration: Controls charging by connecting or disconnecting the Qi receiver.
  - Connections:
    - COM: Connects to Qi receiver positive terminal.
    - NO: Connects to PowerBoost.
    - Control Pin: Connected to D9 on Arduino.
6. APA106 RGB LED
  - Placement: Mounted on the upper layer of the robot for visibility.
  - Integration: Provides visual feedback for charging and battery status.
  - Connections:
    - DIN: Connected to Arduino’s D8 pin.
    - 5V Power: Supplied by PowerBoost.
    - GND: Common ground.

### 4.1.1.2 Power System

1. LiPo Battery (3.7V, 3000mAh)
  - Placement: Positioned at the back of the robot in a custom-designed case to provide protection and stability.
  - Integration: Main power source for the system.
  - Connections:

Positive Terminal:

        - Connected to the PowerBoost’s BAT pin
        - Connected to motor controller through BMS.

Negative Terminal: Common ground

2. Motor Controller and DC Motors
- Placement: The motor controller (Adafruit DRV8833) is mounted on the second layer of the robot, while the DC motors are securely positioned on the lower layer to provide stability and support.
- Integration: The motor controller manages the DC motors, enabling precise speed and directional control. It is powered by the LiPo battery through the BMS, which protects against over-discharge. The controller receives control signals from the Arduino, translating them into motor actions for navigation and movement.
- Connections:
- AIN1/AIN2: Connected to Arduino D3 and D4 for Motor A control.
- BIN1/BIN2: Connected to Arduino D5 and D6 for Motor B control.
- VMOT: Connected to the LiPo battery through the BMS for regulated power.
- GND: Shared ground with all components
3. PowerBoost 1000C
  - Placement: Mounted on the upper layer of the robot near the Arduino to ensure proper ventilation, as the module generates heat during charging and requires airflow for cooling.
  - Integration: Regulates power, providing a stable 5V output for system components and managing battery charging.
  - Connections:
    - BAT: Connects to the positive terminal of the LiPo battery.
    - 5V Output: Powers the Arduino and other 5V components.
    - LBO Pin: Sends low battery status signal to Arduino’s D7.
4. Battery Management System (BMS)
- Placement: Positioned between the LiPo battery and the motor controller to ensure safe power delivery to the motors.
- Integration: The BMS safeguards the LiPo battery by monitoring and regulating its charge and discharge cycles. It prevents overcharging, over-discharging, and short circuits, ensuring stable and safe power delivery to the motor controller. The BMS is essential because the PowerBoost 1000C cannot handle the high current draw required by the motors, making the BMS a critical component for reliable motor operation and overall system safety.
- Connections:
  - Battery Input: Connected to the LiPo battery’s positive and negative terminals.
  - Output Terminals: Connected to the motor controller’s VMOT and GND pins.

### 4.1.1.3 Voltage Divider

1. Battery Voltage Monitoring:
- Purpose: The battery voltage divider is used to monitor the voltage of the LiPo battery (nominal 3.7V) and scale it down to a range readable by the Arduino.
- Resistor Values:
  - R1=3300 Ω
  - R2=10,000 Ω
- Calculation: Using the formula:

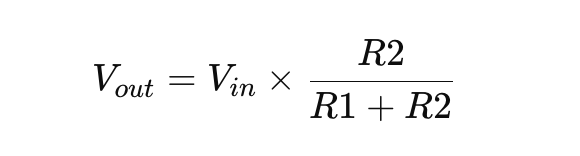
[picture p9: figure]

Assume Vin = 4.2 V (maximum battery voltage):

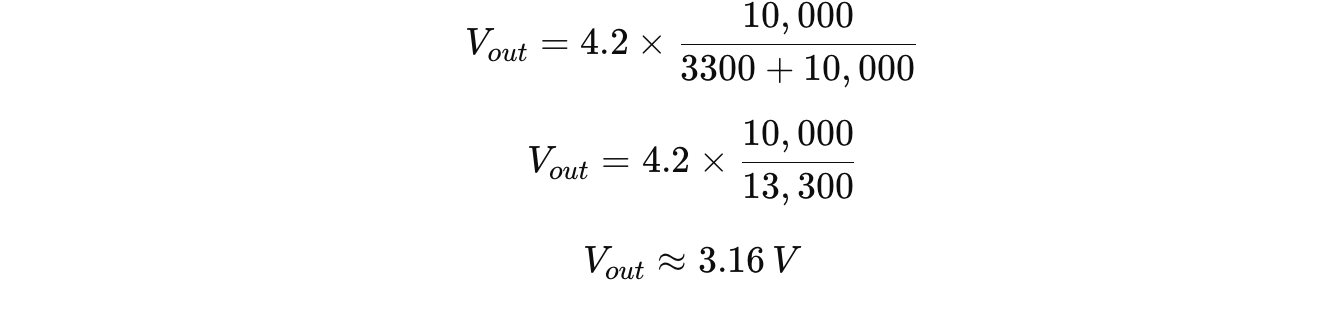
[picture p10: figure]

This ensures the battery voltage is scaled safely for the Arduino’s analog input.

- Integration: Connected to the LiPo battery’s positive terminal and an analog input pin on the Arduino.
2. Receiver Voltage Monitoring:
  - Purpose: Detects when power is being supplied by the Qi wireless receiver, signaling the Arduino that the robot has docked and triggering the charging process.
- Resistor Values:
  - R1=3300 Ω
  - R2=10,000 Ω
- Calculation: Assume Vin = 5 V (voltage output from Qi receiver):

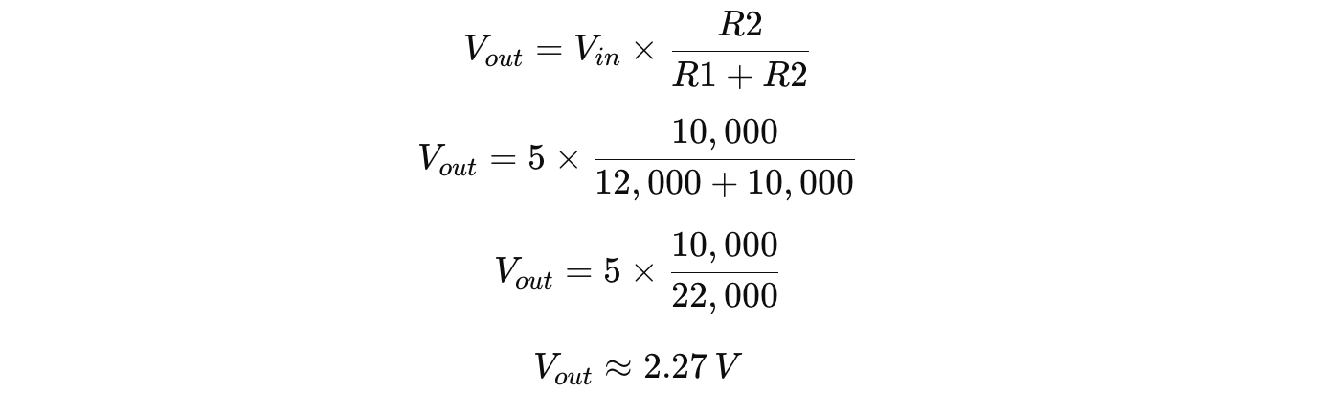
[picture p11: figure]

This output voltage is within the safe range for the Arduino’s analog input to detect the Qi receiver’s power signal.

  - Integration: Connected to the Qi receiver’s output and an analog input pin on the Arduino.

### 4.1.1.4 Graphical Representation

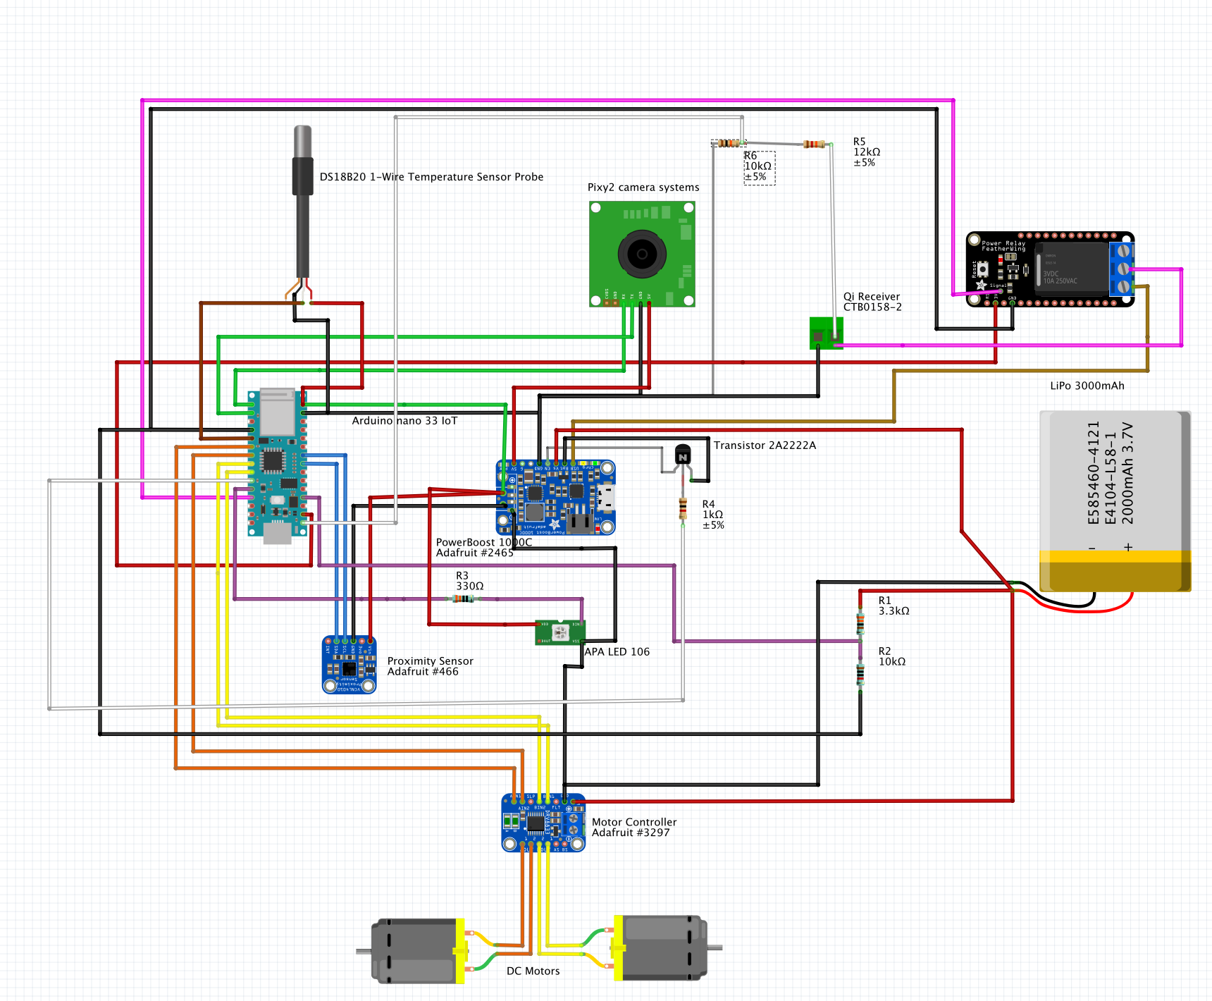
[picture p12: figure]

Figure 5: Robot Wiring Diagram.

The diagram above shows all critical connections, including the Arduino, power distribution, and sensor integrations. This graphical representation complements the detailed descriptions provided for each hardware component, ensuring a comprehensive understanding of the system's configuration.

### Charging Station Components

1. Base
- Placement: Serves as the foundational component of the charging station, positioned on the floor or a stable surface.
- Integration: Houses the Qi wireless charging transmitter and ensures stable alignment for charging. The circular cutout in the base is specifically designed to securely hold the transmitter in place, optimizing energy transfer during the charging process.
- Specifications: it features pre-drilled holes for mounting components, ensuring stability and alignment.

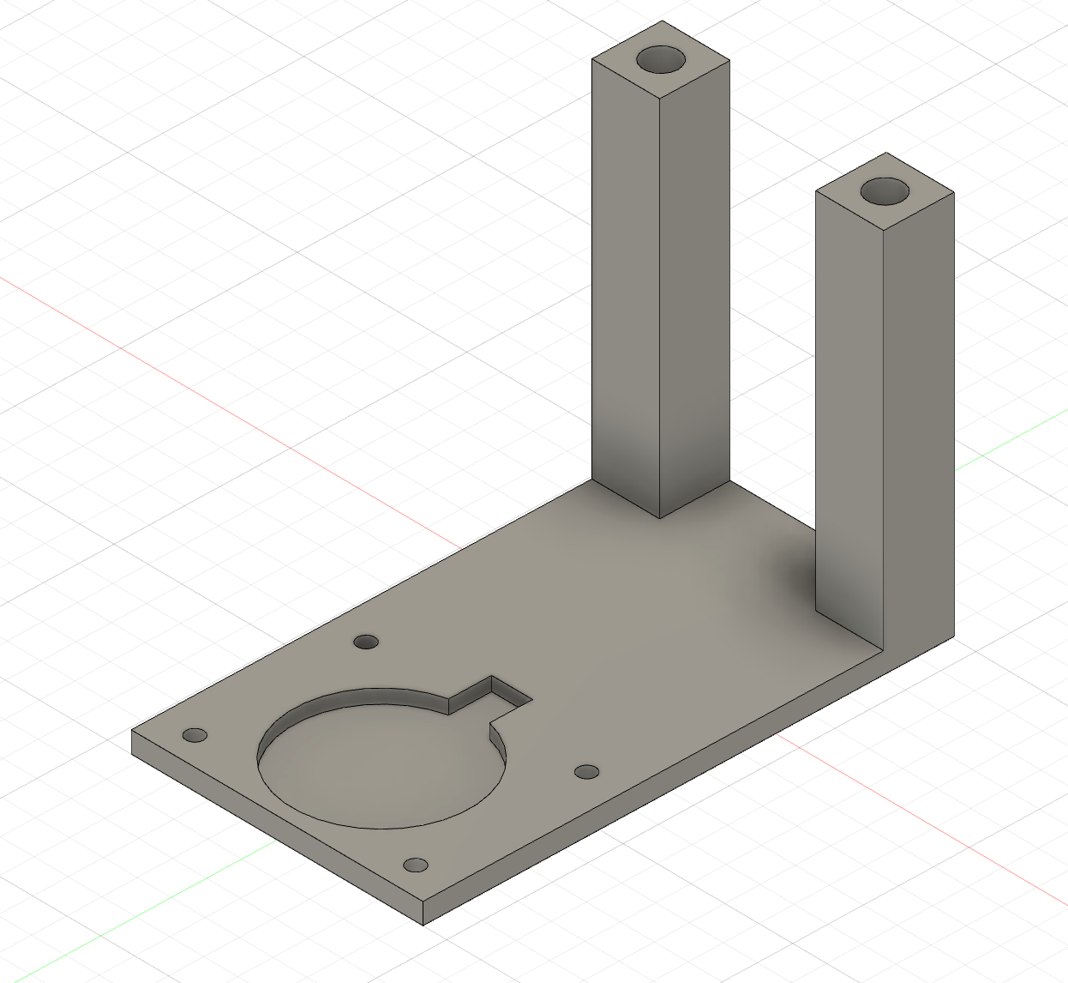
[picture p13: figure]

Figure 6. Charging Station -Base

2. Rising Edge Docking Guide
  - Placement: At the entry of the charging station’s docking pad.
  - Integration: Guides the rover into correct alignment.
  - Specifications: Sloped edges to facilitate alignment.

The base includes a rising edge and block system that guides the robot into the correct docking position, securing it in place during the charging process

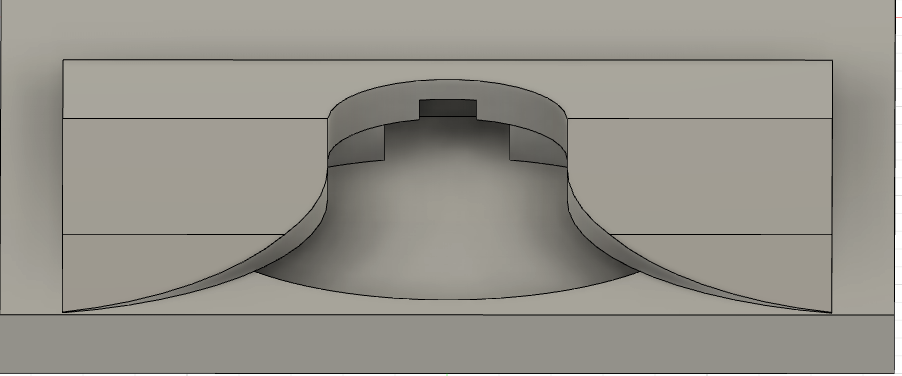
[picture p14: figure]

Figure 7. Base Rising Edge

3. Circular Docking Feature
  - Placement: Centered above the Qi transmitter on the charging pad.
  - Integration: Holds the rover securely during charging.
  - Specifications: Circular ridge for alignment.

Chassis: The robot’s chassis incorporates a circular docking feature that integrates smoothly with the rising edge and block on the base. This ensures precise alignment with the transmitter for effective wireless charging.

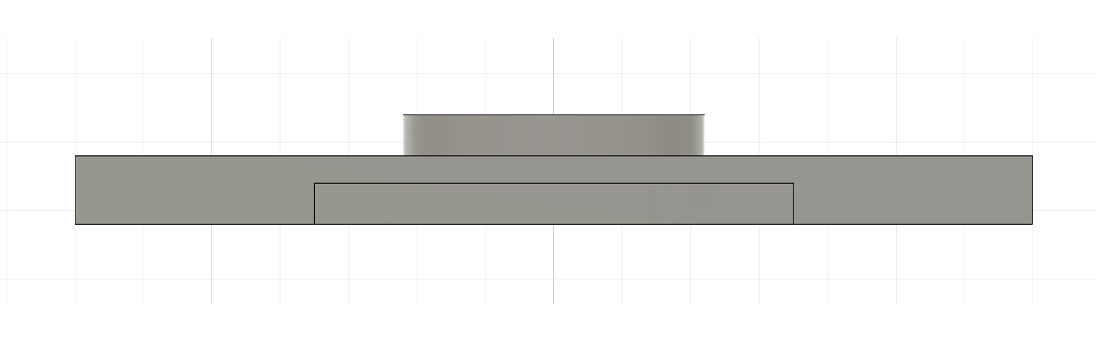
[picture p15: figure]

Figure 8: Circular Docking Feature

4. Cooling Fan with Mount
  - Placement: Near the Qi transmitter for heat dissipation.
  - Integration: Maintains safe temperatures during prolonged charging.
  - Control: Manually operated by the user.
- The fan mount is positioned above the robot to regulate the temperature during charging. Its adjustable design allows for precise positioning overheat-sensitive areas, providing optimal cooling for the PowerBoost 1000C charger.

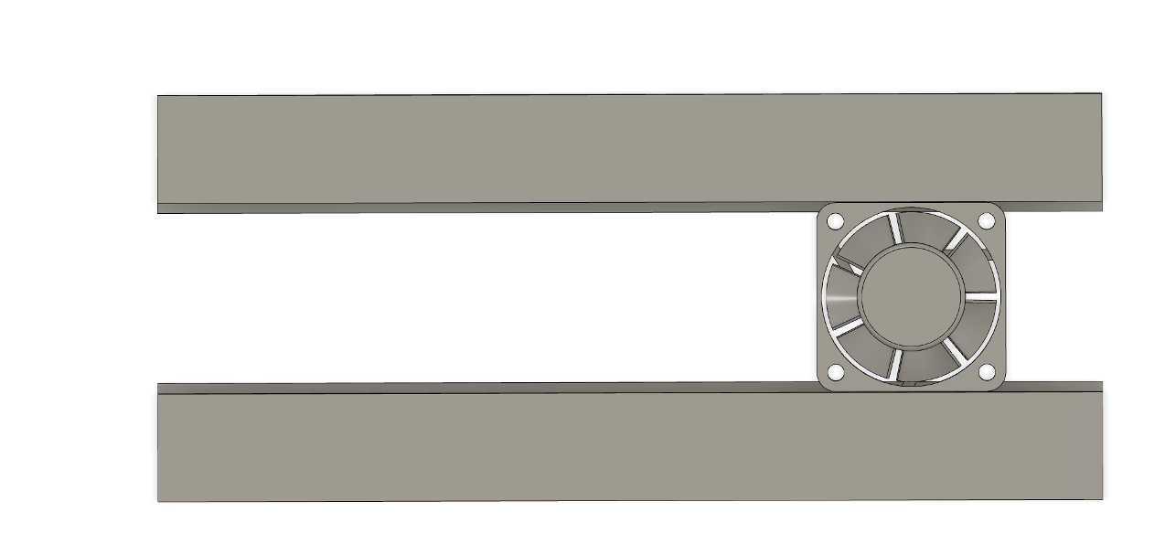
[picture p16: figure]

Figure 9. Fan Mount for cooling the Charger

5. Complete Design
- Placement: The charging station is designed as a single integrated unit, positioned on a stable surface to provide consistent functionality.
- Integration: Combines all individual components (base, rising edge, docking guide, and cooling fan) into a cohesive structure. The charging station seamlessly aligns with the BID4R robot during docking, ensuring proper positioning and efficient wireless charging.
- Specifications: The design includes structural supports for stability, precise cutouts for the Qi transmitter and fan, and an ergonomic layout to guide the robot into the docking position effortlessly.

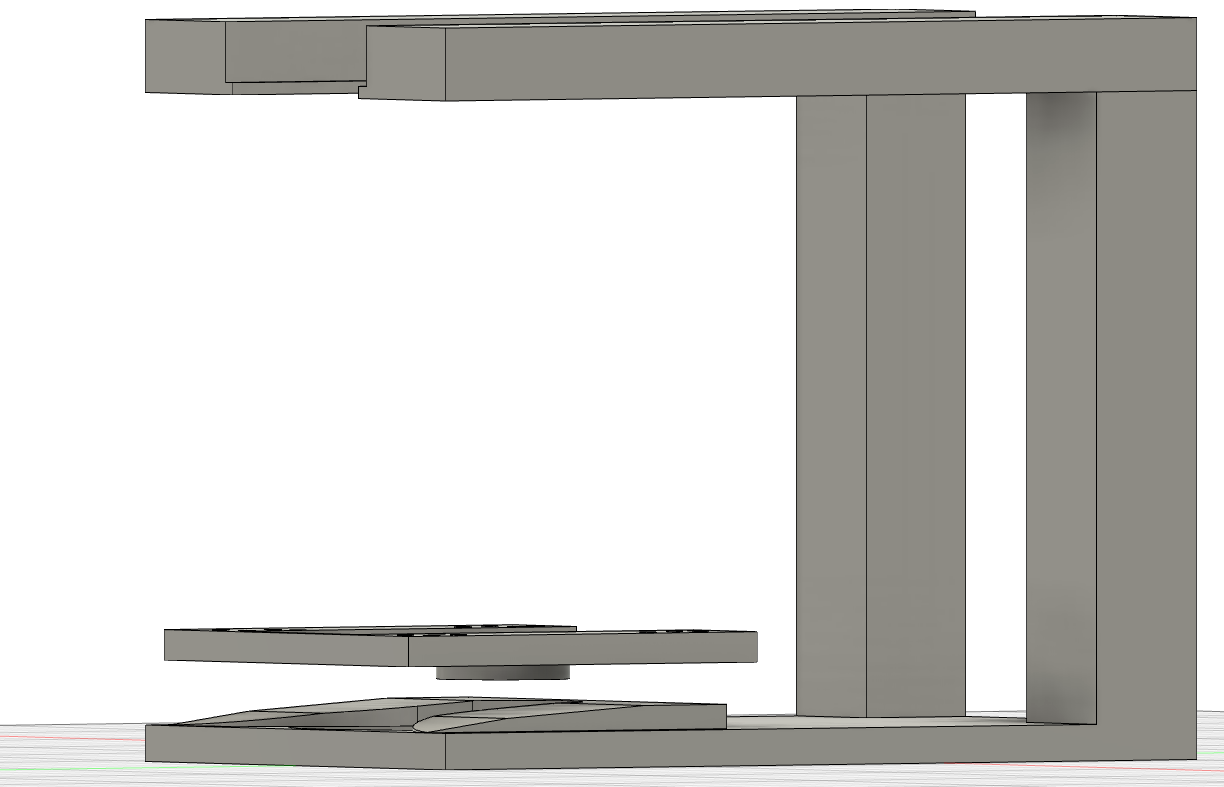
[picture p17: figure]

Figure 10: Complete Design of the Charging Station

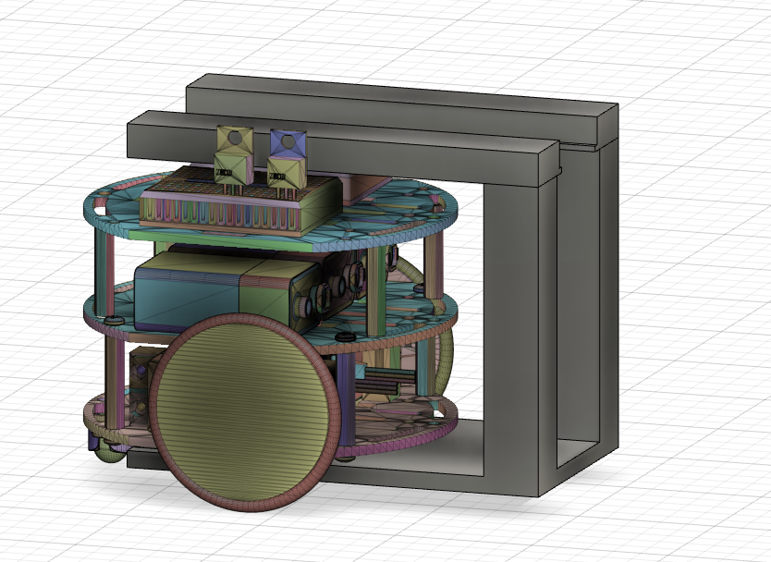
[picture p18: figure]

Figure 11: Robot Docking on the Charging Station

This image illustrates the integration of the BID4R robot with the charging station. The docking process demonstrates how the robot aligns with the rising edge and block system, ensuring proper positioning over the Qi transmitter for efficient wireless charging. This setup highlights the seamless interaction between the robot and the charging station.

## 4.2. Software Detailed Design

This section provides a comprehensive overview of each software module within the BID4R system. Each module includes functionality, conditions for execution, processing logic, interfaces, and any relevant security requirements. Additionally, graphical representations and flow diagrams are provided for each module to visually demonstrate the module's flow and logic.A narrative description of each module, its function(s), the conditions under which it is used (called or scheduled for execution), its overall processing, logic, interfaces to other modules, interfaces to external systems, security requirements, etc. Explain any complex algorithms used by the module in detail

### Setup and Initialization Module

- Function: Initializes all sensors, pins, and communication protocols at system startup.
- Conditions: This module is called once at the start of the system.
- Logic: Sets up serial communication, sensors, LED indicators, motor pins, and charging controls.
- Graphical Representation:

Figure 12: Setup and Initialization Flow Diagram.

### Main Loop Module

- Function: Acts as the primary loop of the system, monitoring battery voltage, temperature, and charging status.
- Conditions: Runs continuously after system setup.
- Logic: Determines if the system is in charging mode or normal operation and updates LED indicators accordingly.
- Graphical Representation:

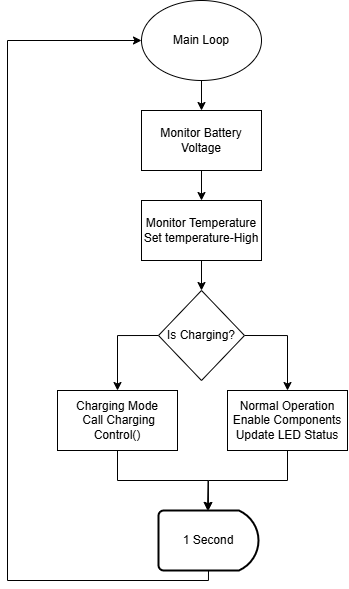
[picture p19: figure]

Figure 13: Main Loop Flow Diagram.

### Temperature Monitoring Module

- Function: Continuously reads the temperature sensor data and provides feedback to the main control system.
- Conditions: Called at regular intervals to ensure safe operating temperatures.
- Logic: Requests temperature data from the DS18B20 sensor and checks against predefined thresholds.
- Graphical Representation:

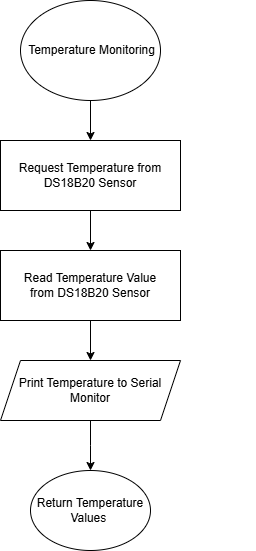
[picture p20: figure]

Figure 14: Temperature Monitoring Flow Diagram.

### Battery Monitoring Module

- Function: Reads and calculates the battery voltage through a voltage divider, enabling battery status monitoring.
- Conditions: Monitored at regular intervals during operation.
- Logic: Converts analog voltage readings to digital values and calculates actual voltage using a predefined formula.
- Graphical Representation:

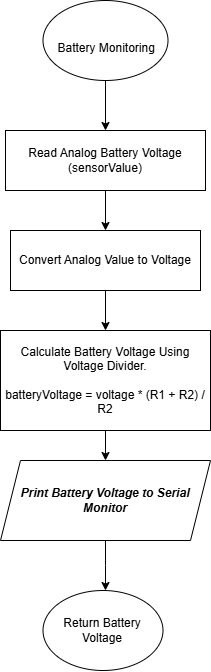
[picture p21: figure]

Figure 15: Battery Monitoring Flow Diagram.

### Charging Control Module

- Function: Manages charging operations by enabling or disabling the relay to the Qi wireless charging receiver based on battery and temperature data.
- Conditions: Engages when charging is detected
- Logic: Monitors battery voltage and temperature to control charging and prevent overcharging.
- Graphical Representation:

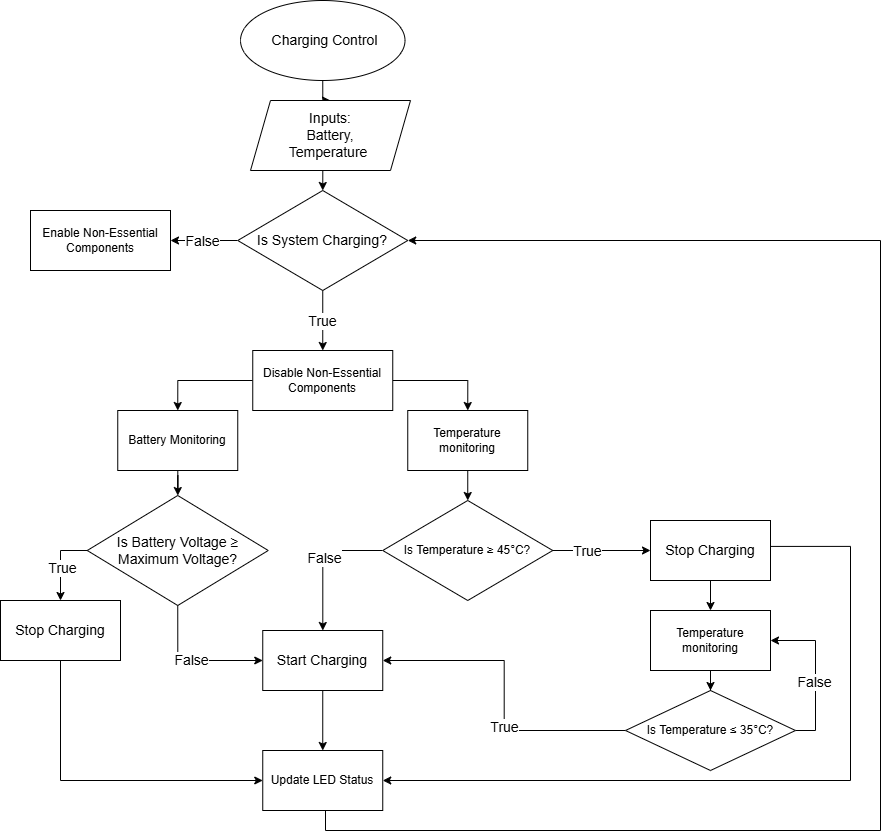
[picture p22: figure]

Figure 16: Charging Control Flow Diagram.

### LED Status Module

- Function: Manages the LED indicators to display system status, including battery level, charging status, and temperature alerts.
- Conditions: Activated by changes in battery level, charging status, or temperature.
- Logic: Displays different colors and flashing patterns based on system status.
- Graphical Representation:

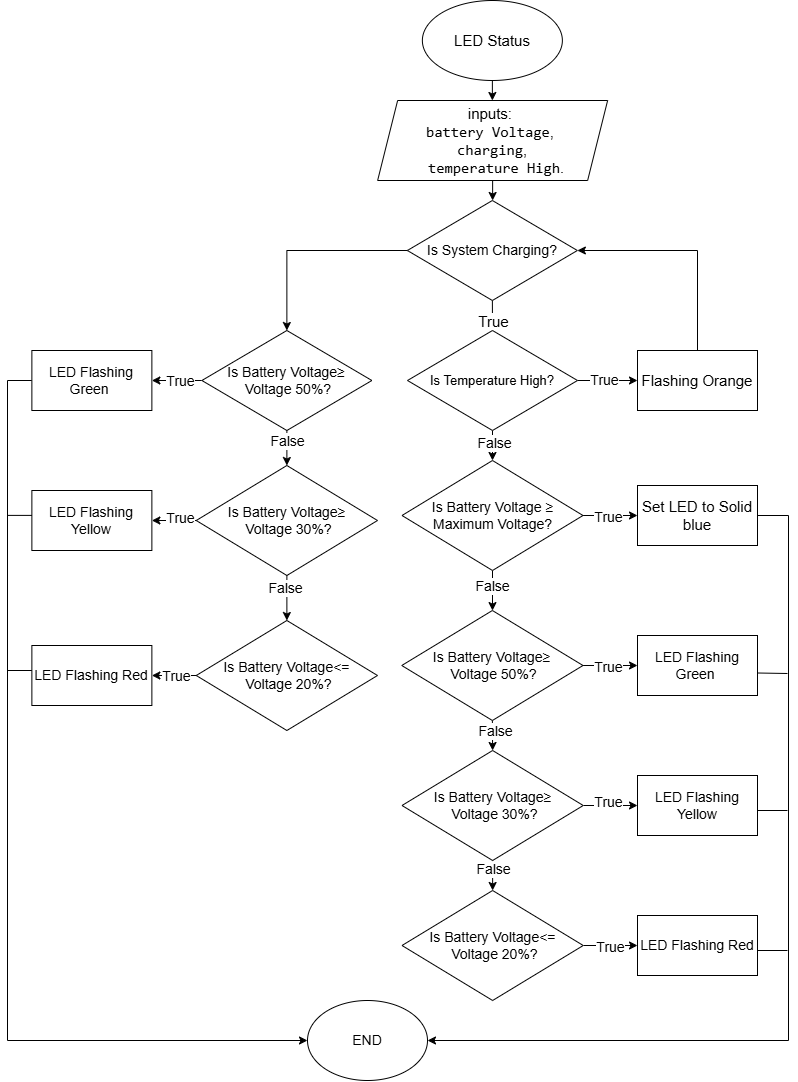
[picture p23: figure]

Figure 17: LED Status Flow Diagram.

## 4.3. Internal Communications Detailed Design

This section provides an in-depth look at the internal communication architecture of the BID4R system, expanding upon the high-level overview provided in Section 2.3. Here, we detail the design, protocols, data formats, and specific connectivity requirements that enable seamless interaction among the system's components. The communication design is critical for managing power, ensuring safe charging, and providing operational feedback to the user.

### Communication Protocols

1. I2C (Inter-Integrated Circuit)
  - Description: The I2C protocol is used for communication between the Arduino Nano and certain sensors, such as the proximity sensor. I2C allows multiple devices to share the same bus, enabling efficient data transfer with minimal wiring.
  - Functionality:
- The Arduino Nano acts as a master device, sending requests and receiving data from slave devices.
- Example: The proximity sensor is connected via the I2C bus using pins A4 (SDA) and A5 (SCL), allowing the Arduino to receive alignment data during docking.
2. UART (Universal Asynchronous Receiver-Transmitter)
- Description: UART is primarily used for communication with external modules, such as the Pixy2 camera system, which is part of the pre-existing setup for the rover.
- Functionality:
- The Arduino Nano communicates with the Pixy2 camera over serial lines using pins D0 (RX)and D1 (TX).
- Example: While the Pixy2 camera provides vision-based data for potential enhancements, it is not directly involved in the BID4R project scope but remains part of the original rover design.
3. GPIO (General Purpose Input/Output)
- Description: GPIO pins on the Arduino are utilized for control and signaling, allowing basic on/off functionality for components such as the relay, motor controller, and LED indicators.
- Functionality:
    - Temperature Sensor: Sends temperature readings to the Arduino through D4 (GPIO) for thermal monitoring during charging.
    - LED Indicators: Controlled via D8 (GPIO), the RGB LED provides visual feedback on the battery status using various colors and patterns.
    - Example: The Arduino uses GPIO pins to activate the relay (D9), monitor temperature (D4), and update LED status (D8).
4. Analog Input
- Description: Analog input pins are used to read variable voltage levels, such as the battery’s voltage, through a voltage divider circuit.
- Functionality:
  - Battery Voltage Monitoring: The Arduino reads the battery voltage via pin A0 (Analog Input). This scaled-down voltage signal is used to assess the battery level and control the charging process.
  - Example: The analog input allows real-time monitoring of the battery’s voltage and updates the LED indicator and relay status accordingly.

### Communication Paths

The communication paths within the system connect new and existing components, enabling efficient data transfer and control signals. Below is an overview of the primary communication pathways:

- Data Flow from Sensors to Arduino:
  - The temperature sensor sends thermal data to the Arduino via D4 (GPIO), allowing the system to monitor conditions during charging.
  - The proximity sensor, connected via A4 (SDA) and A5 (SCL), provides alignment data to assist with docking.
  - The battery voltage divider, connected to A0 (Analog Input), provides real-time voltage data for safe charging.
- Control Signals for Charging:
  - The Arduino sends signals via D9 (GPIO) to the relay, activating or deactivating charging based on battery level and temperature conditions.
- LED Status Updates:
  - Using D8 (GPIO), the Arduino controls the RGB LED indicators to display the battery status with various colors and patterns.
- Existing Components:
  - The proximity sensor (I2C), Pixy2 camera (UART), and motor controller (GPIO) are pre-existing components in the rover. While interfaced with the Arduino, they remain outside the primary scope of the BID4R project but demonstrate the system's capability to manage multiple communication protocols.

Figure 18. Internal Communications Diagram. (explained in section 2.3)

# 5. External Interfaces

External systems that interact with the BID4R system include pre-existing components such as sensors, cameras, motor controllers, and DC motors. These components play critical roles in the rover’s operation and interface with the Arduino Nano. While their functionality remains unchanged and independent of BID4R-specific enhancements, they are essential for the project’s success.

## 5.1. Hardware Interface Architecture

The BID4R system integrates pre-existing hardware components to achieve navigation and mobility. These components include:

- Proximity Sensor (VCNL4010):
  - Function: Measures distance to nearby objects, providing data for docking alignment and collision avoidance.
  - Communication: Two-way communication with the Arduino over I2C.
- Pixy2 Camera:
  - Function: Detects objects using color and shape recognition, aiding navigation and alignment.
  - Communication: Two-way communication with the Arduino via SPI.
- Motor Controller:
  - Function: Controls the DC motors based on Arduino signals, enabling precise movement and direction control.
  - Communication: Receives one-way commands from the Arduino through GPIO.
- DC Motors:
  - Function: Provide mobility for the rover by responding to motor controller commands.
  - Communication: Controlled indirectly by the Arduino via the motor controller.

## 5.2. Hardware Interface Detailed Design

This section consolidates the technical details and interactions between the BID4R system and external hardware components:

- Proximity Sensor (VCNL4010):
  - Uses IR-based detection to measure distances in millimeters.
  - Data Flow: Sends real-time data to the Arduino for processing.
- Pixy2 Camera:
  - Transmits object detection data in structured packets (e.g., coordinates, dimensions).
  - Data Flow: Continuously monitors surroundings and sends object details to the Arduino.
- Motor Controller:
  - Adjusts motor speed and direction based on digital signals from the Arduino.
  - Data Flow: Processes one-way commands to control rover movement.
- DC Motors:
  - Executes movement commands as directed by the motor controller.
  - Data Flow: Operates directly under motor controller input.

## 5.3. Software Interface Architecture

The BID4R system’s software interfaces enable efficient communication between the Arduino and external components. Each interface handles specific data flows:

- Pixy2 Camera Interface:
  - Protocol: SPI for high-speed communication.
  - Data Flow: Transfers object detection data to the Arduino.
- Motor Control Interface:
  - Protocol: GPIO for direct motor control.
  - Data Flow: Arduino sends HIGH/LOW signals for motor adjustments.
- Proximity Sensor Interface:
  - Protocol: I2C for regular distance measurement updates.

Data Flow: Arduino queries proximity data for docking alignment

## 5.4. Software Interface Detailed Design

5.4 Software Interface Detailed Design

Details for each software interface include data formats, protocols, and error management:

- Pixy2 Camera:
  - Data: Transmits structured object data packets.
  - Error Handling: Retries transmission if communication fails.
- Motor Controller:
  - Data: Receives HIGH/LOW signals for speed and direction control.
  - Error Handling: Defaults to stopping motors on signal loss.
- Proximity Sensor:
  - Data: Sends distance values in millimeters.
  - Error Handling: Retries data requests if no response is received.

## 5.5. Internal Communication

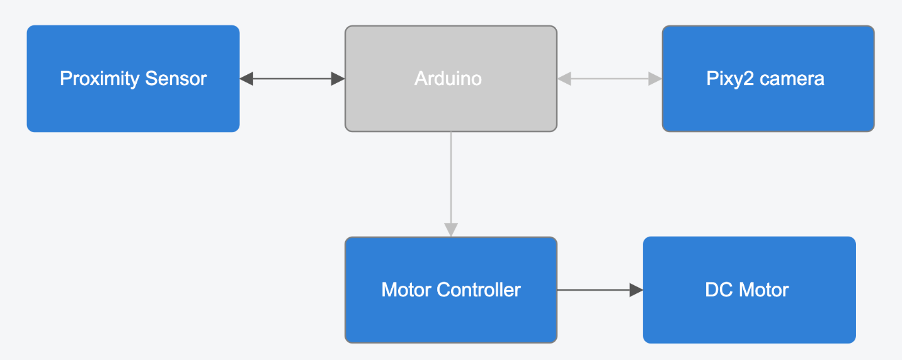
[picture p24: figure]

Figure 19: Overview of Component Interactions

This diagram illustrates the interaction pathways between components and the Arduino, highlighting its dual role of operating the robot’s systems and managing the battery system.

- Proximity Sensor ↔ Arduino:
  - Two-way communication.
  - The sensor provides alignment data to the Arduino, which processes the input.
- Pixy2 Camera ↔ Arduino:
  - Two-way communication.
  - The camera sends object data to the Arduino, which processes it for alignment tasks.
- Arduino → Motor Controller:
  - One-way communication.
  - Sends control signals for movement.
- Motor Controller → DC Motor:
  - One-way communication.
  - Directs motor speed and direction as instructed by the Arduino.

The faded Arduino in the diagram highlights its dual role: operating the robot’s systems (sensors, camera, and motor control) and managing the battery system simultaneously.

<BID4R> System Design Document

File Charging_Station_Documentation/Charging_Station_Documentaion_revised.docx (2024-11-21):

BID4R Charging Station

Design Documentation

Prepared by: Turki Alturki

Course: EE 421

Date: October 2024

Abstract

This document outlines the design and implementation of the BID4R wireless charging station using Qi technology. The charging station was designed to ensure efficient power transfer, precise docking alignment, and adequate thermal management. The design process involved addressing several challenges, such as limited height clearance and repositioning of components to accommodate the robot's unique configuration.

Table of Contents

1. Introduction

2. Design Requirements and Specifications

3. Design Approach

3.1 Conceptual Design

3.2 Final Design

4. Challenges and Revisions

5. Testing and Validation

6. Conclusion

7. References

8. Appendix

1. Introduction

The BID4R charging station is designed to facilitate wireless charging using Qi technology. This system consists of a base for housing the Qi transmitter and a chassis on the robot for the Qi receiver. The goal of this design is to ensure precise alignment, efficient power transfer, and thermal management during charging while addressing physical constraints imposed by the robot's structure.

The initial design concept was found on GitHub, and modifications were made to suit the specific needs of the BID4R project.

2. Design Requirements and Specifications

- Functional Requirements:
- Wireless Charging: The charging station must enable efficient wireless charging through the Qi transmitter and receiver.
- Docking Alignment: The robot should dock securely to ensure optimal charging.
- Thermal Management: A fan should be incorporated to cool the PowerBoost 1000C charger during the charging process.
- Non-Functional Requirements:
- Easy Assembly/Disassembly: The station should be simple to assemble and disassemble for maintenance.
- Adjustable Fan Position: The fan's position must be adjustable to ensure efficient cooling.
- Accommodation of Robot Height: The station must be designed to account for the 16mm ground clearance of the robot.

3. Design Approach

3.1 Conceptual Design

The initial design for the charging station, sourced from GitHub, featured a two-layer base. The lower layer was intended to house the Qi transmitter, while the upper layer would accommodate docking. The conceptual design also included wire management with wires exiting from the front of the station.

3.2 Final Design

Due to height limitations and functional challenges, the two-layer system was eliminated. Here is the final design description:

- Base: The Qi transmitter is placed visibly on the surface of the base for direct alignment with the Qi receiver, ensuring efficient power transfer. The base includes a rising edge and block system that guides the robot into the correct docking position, securing it in place during the charging process. Instead of wires exiting from the front, they are now routed out the back, preventing interference with the docking process.


Figure 1: Rising Edge and Block for Precise Docking here

- Chassis: The robot’s chassis incorporates a circular docking feature that integrates smoothly with the rising edge and block on the base. This ensures precise alignment with the transmitter for effective wireless charging.


Figure 2: Circular Docking Feature

- Fan: The fan mount is positioned above the robot to regulate the temperature during charging. Its adjustable design allows for precise positioning over heat-sensitive areas, providing optimal cooling for the PowerBoost 1000C charger.


Figure 3: Fan Mount for Cooling the Charger

4. Challenges and Revisions

- Challenge 1: Height Limitation for Base Layers

The initial design included two layers for the base, with the Qi transmitter housed in the bottom layer. However, the robot's 16mm ground clearance was insufficient for this design. To resolve this, the bottom layer was removed, and the Qi transmitter was placed directly on the base floor.

- Challenge 2: Wire Placement

In the initial design, wires exited from the front of the charging station, where the robot docks. This caused interference during docking, as the robot would come into contact with the wires. To solve this, the wires were rerouted to the back of the station, keeping them clear of the robot's docking path.

- Revision: Removal of the Wire Management Box The initial design included a dedicated box to house and manage wires and circuit boards. However, to simplify the design, this box was removed. The wires are now routed and secured along the base, maintaining neat organization without additional housing. This revision reduces the station's complexity while still ensuring a clean layout.
- Challenge 3: Robot Configuration

The initial design assumed a two-wheel robot. However, the BID4R robot has two wheels and a stabilizer in the middle, which limited its ability to dock fully. To accommodate this, the transmitter was moved to the front of the station, allowing the robot to dock properly, with all wires and components positioned at the back.

5. Testing and Validation

- Docking Tests: Tests will ensure the robot docks accurately and maintains a stable connection for charging. The design's alignment features, such as the rising edge and block system, will be tested for precision.
- Charging Efficiency Tests: The Qi transmitter and receiver will be evaluated for consistent power transfer, ensuring the robot can charge effectively without interruptions.
- Thermal Tests: Temperature sensors will be used to monitor the PowerBoost 1000C during charging, ensuring the fan maintains safe operating temperatures. The adjustable fan will be tested to optimize its cooling effectiveness.

6. Conclusion

The BID4R charging station design successfully addresses both functional and physical constraints. The design ensures efficient wireless charging through the precise alignment of the Qi transmitter and receiver while providing thermal management through an adjustable fan. Key revisions, such as repositioning the transmitter and rerouting wires, resolved issues related to height and docking. Future improvements could focus on optimizing the charging distance and further refining the thermal management system.

7. References

- GitHub Repository: https://github.com/kevinmcaleer/Wireless-Charging-STLs

8. Appendix


Figure 4: Initial design


Figure 4: Revised design

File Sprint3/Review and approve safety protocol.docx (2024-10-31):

### Review and Approve Safety Protocol:

To conduct a thorough review and approval of the safety protocol, the following areas should be examined in detail to ensure the protocol comprehensively addresses potential risks and is ready for implementation and testing.

#### 1. Battery Safety and Handling:

- Storage Requirements: Ensure that the protocol specifies proper storage conditions for Lithium Polymer (LiPo) batteries. This includes maintaining a cool, dry environment away from direct sunlight, ideally between 68°F and 77°F. Storage guidelines should emphasize avoiding environments that could lead to overheating or chemical instability, which could compromise battery integrity.
- Charging Protocols: Confirm that only chargers designed for LiPo batteries are allowed, avoiding incompatible chargers that could cause dangerous overcharge or overheating. The safety protocol should mandate close monitoring during charging, including a recommendation to avoid leaving batteries unattended on chargers for prolonged periods or overnight.
- Battery Health Monitoring: The protocol should include regular checks for early signs of battery degradation. Health indicators, such as swelling, unusual warmth, or physical damage, should trigger immediate removal of the battery from use and preparation for safe disposal.

#### 2. Thermal and Power Management:

- Thermal Monitoring and Cutoff: Ensure the protocol details the system's thermal monitoring mechanisms, including actions if the battery exceeds the safe operating temperature threshold (113°F or 45°C). This may involve automated power cuts or alerts to prevent further charging and avoid battery overheating.
- Battery Management System (BMS): The protocol should specify the role of the BMS in monitoring battery voltage and current, providing safeguards against overcharging, over-discharging, and short-circuit risks. BMS functionality should be detailed to highlight the protections in place and ensure the system maintains battery health and longevity.
- Current Draw Limitations: Ensure the protocol enforces power draw restrictions to prevent battery overload. The system should monitor components that might increase current beyond safe levels, allowing for safe power usage distribution across all connected devices.

#### 3. Operational Safety Measures:

- Charging Station Safety: Verify that the protocol includes safe operating instructions for the wireless charging station, emphasizing correct alignment procedures and safety checks for wireless power transfer efficiency. The protocol should also outline procedures for safely initiating and halting charging, including LED-based indicators to confirm charge status at each stage (low, half-full, full).
- User Guidance and LED Indicators: Ensure the protocol includes clear instructions on interpreting LED indicators for battery charge levels, which will help operators gauge when to charge or remove the rover. LED indications should serve as the primary interaction point for operators, so the protocol should explain each LED signal and corresponding action, particularly during high-temperature cutoffs.
- Safety Documentation and Accessibility: Confirm that safety information is well-documented and accessible to operators and developers involved in the system's maintenance. This should include visual aids for proper setup, alignment guides for docking, and response protocols in case of unexpected signals or malfunctions.

#### 4. Emergency and Disposal Protocols:

- Emergency Handling and System Shutdown: The protocol should detail emergency responses in case of battery overheating or leakage, with procedures for safe removal and shutdown. Clear instructions for isolating affected components and the rover itself should be outlined to prevent potential hazards.
- Battery Disposal: Ensure safe disposal guidelines for LiPo batteries, outlining proper disposal methods to comply with local regulations. Batteries should be prepared for disposal by taping terminals to prevent short circuits, and arrangements should be made for transfer to certified recycling facilities.

By addressing each of these components, the safety protocol can effectively minimize risks associated with battery and charging operations, ensuring readiness for safe testing and deployment. Approval should be granted once all steps are confirmed to align with established safety standards and provide clear, actionable guidance to all users.

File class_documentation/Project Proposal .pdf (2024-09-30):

## Project Proposal

Project Name: BID4R Rover Model Project Team Members:
Turki Alturki
Belal Abed
Mohammed Alasmari
Problem Statement:
The Biologically Inspired Resilient Systems Test Arena (BIRSTA) currently operates with a swarm of 50 rovers powered by AA batteries, providing a short operational time of approximately 15 minutes. This limits the testing and research capabilities of the system, as the rovers require frequent recharging or battery replacements. The goal of this project is to develop a power distribution system using Lithium Polymer (LiPo) batteries,
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

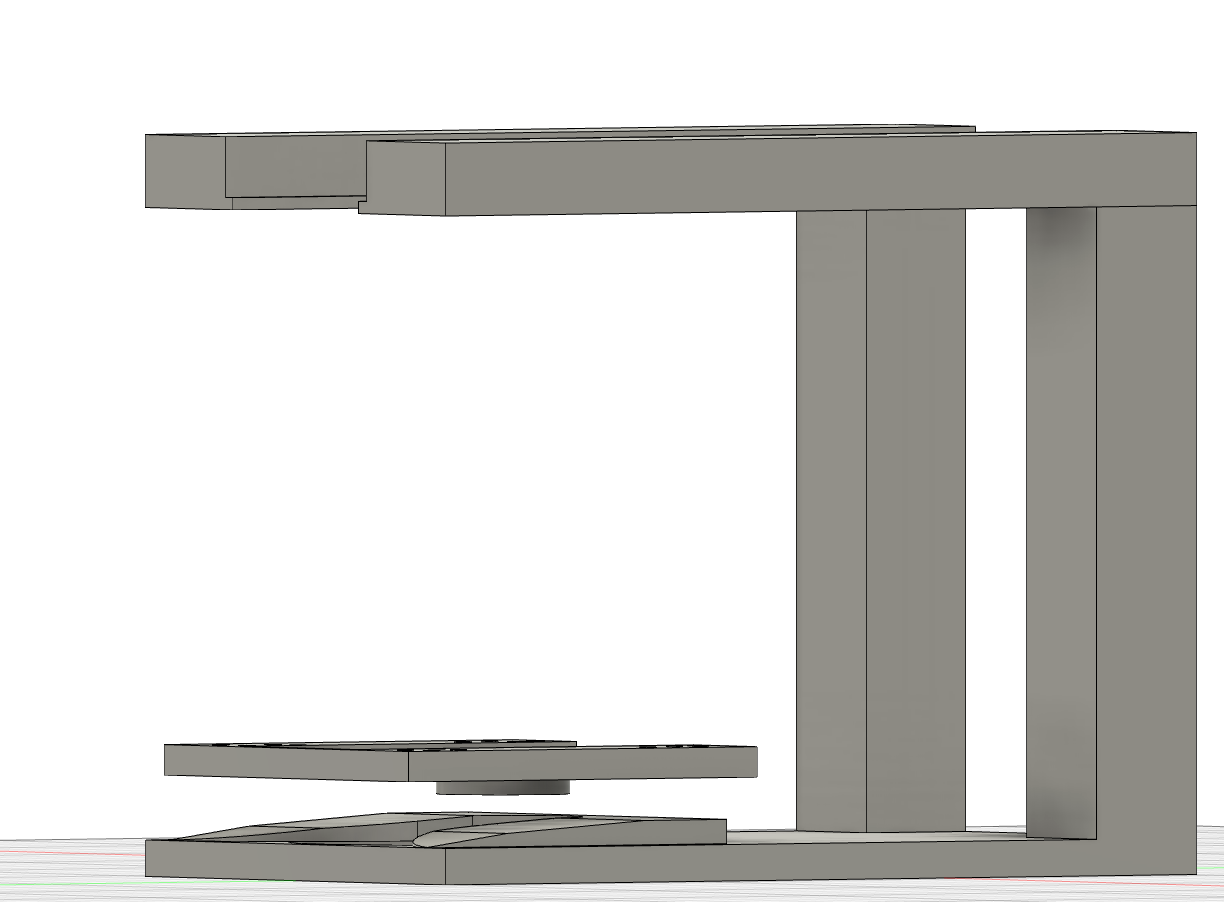
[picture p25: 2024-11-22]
Charging_Station_Documentation/Images/Screenshot 2024-11-20 at 4.29.43 AM.png

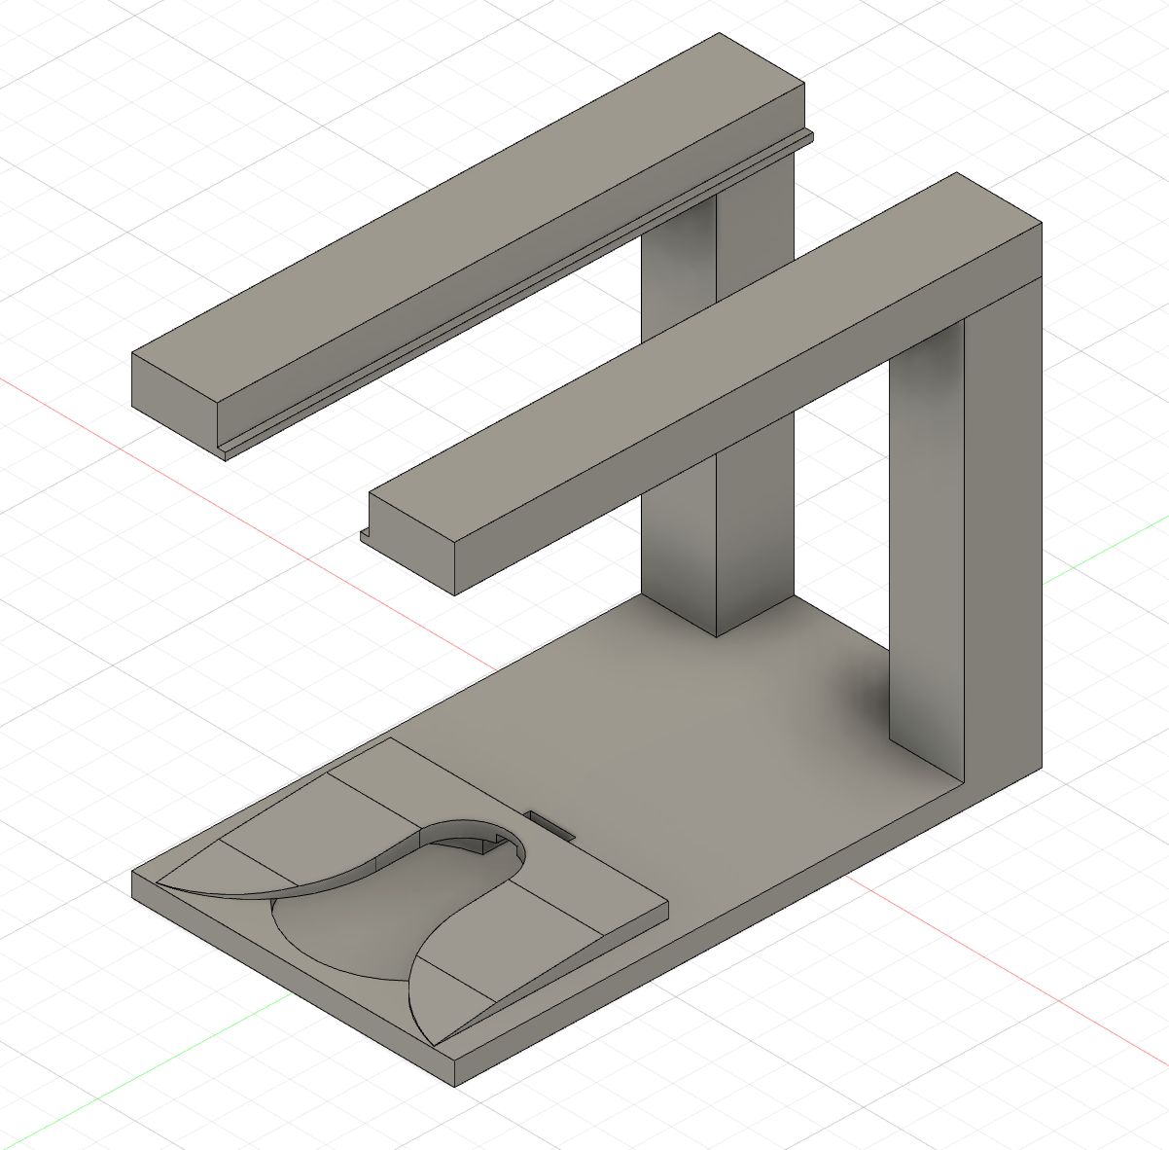
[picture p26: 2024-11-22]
Charging_Station_Documentation/Images/Screenshot 2024-11-20 at 4.06.01 AM.png

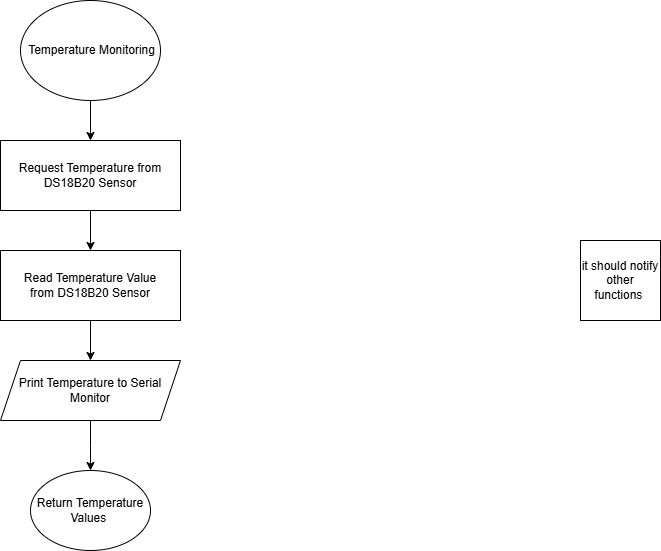
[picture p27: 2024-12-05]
Code_Documentation/Temperature_Monitoring.drawio.png

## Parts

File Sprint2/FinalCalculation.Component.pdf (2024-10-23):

# BID4R Project - Final Power-Flow Calculations

### 1. Power Consumption of Each Component

We calculate the power consumption using the formula: P = V × I

Where:

- P is power in watts (W)
- V is voltage in volts (V)
- I is current in amps (A)

Motors (powered directly by LiPo):

Normal operation (per motor): P = 3.7V × 0.3A = 1.11W For two motors: 1.11W × 2 = 2.22W
Stall condition (per motor): P = 3.7V × 1.5A = 5.55W
For two motors: 5.55W × 2 = 11.1W

Pixy2 Camera (powered by PowerBoost 1000C): P = 5V × 0.14A = 0.7W

VCNL4010 Proximity Sensor (powered by PowerBoost 1000C): P = 5V × 0.008A = 0.04W

Arduino Nano 33 IoT (powered by PowerBoost 1000C): P = 5V × 0.16A = 0.8W

APA106 LED (powered by PowerBoost 1000C): P = 5V × 0.06A = 0.3W

DS18B20 Temperature Sensor (powered by PowerBoost 1000C): P = 5V × 0.0015A = 0.0075W

Adafruit Power Relay FeatherWing (powered by PowerBoost 1000C): P = 5V × 0.02A = 0.1W

### 2. Total Power Consumption

The total power consumption is the sum of the motors and the PowerBoost-powered components:

Normal operation:

Power consumption of the motors: 2.22W

Power consumption of the components powered by the PowerBoost:
- Pixy2 Camera: 0.7W
- VCNL4010 Proximity Sensor: 0.04W
- Arduino Nano 33 IoT: 0.8W
- APA106 LED: 0.3W
- DS18B20 Temperature Sensor: 0.0075W
- Power Relay FeatherWing: 0.1W

Summing up the PowerBoost components: P_PowerBoost (normal) = 1.9475W

Thus, the total power consumption during normal operation is:

P_total (normal) = 2.22W + 1.9475W = 4.1675W

Stall condition:

Power consumption of the motors: 11.1W

Power consumption of the components powered by the PowerBoost remains the same: P_PowerBoost (stall) = 1.9475W

Thus, the total power consumption during stall condition is:

P_total (stall) = 11.1W + 1.9475W = 13.0475W

### 3. PowerBoost Efficiency

The PowerBoost 1000C operates at 90% efficiency. The power drawn from the battery by the PowerBoost is:

P_battery for PowerBoost = P_PowerBoost / Efficiency

For both normal and stall conditions, the PowerBoost is drawing the same power:

P_battery for PowerBoost = 1.9475W / 0.9 ≈ 2.16W

### 4. Battery Capacity and Energy Stored

The energy stored in the LiPo battery is calculated as:

E_battery = Capacity (Ah) × Voltage (V)

For a 3Ah, 3.7V battery: E_battery = 3Ah × 3.7V = 11.1Wh

### 5. Battery Runtime Estimate

We estimate the battery runtime using: Runtime = E_battery / P_total

For normal operation: Runtime (normal) = 11.1Wh / 4.1675W ≈ 2.66 hours ≈ 159 minutes

For stall conditions: Runtime (stall) = 11.1Wh / 13.0475W ≈ 0.85 hours ≈ 51 minutes

### 6. Current Draw Monitoring

We ensure the PowerBoost 1000C's current draw is within the 1A limit. The total current draw is:

I_total PowerBoost = I_Pixy2 + I_VCNL4010 + I_Arduino + I_LED + I_DS18B20 + I_Relay

Substituting values: I_total PowerBoost = 0.14A + 0.008A + 0.16A + 0.06A + 0.0015A + 0.02A = 0.3895A

This is within the 1A limit of the PowerBoost.

### 7. Charging Time for the Battery

The time required to charge the battery using the Qi wireless charging system is estimated using the following formula:
Charging Time = E_battery / P_charging
Given the Qi charger provides 5W with 80% efficiency, the power delivered to the battery is:
P_charging = 5W × 0.8 = 4W
Thus, the charging time is:
Charging Time = 11.1Wh / 4W ≈ 2.78 hours ≈ 2 hours and 47 minutes

### 8. (BMS and Fuses)

The Battery Management System (BMS) included in the design will not significantly affect the power consumption or runtime calculations, as its primary function is to protect the battery from overcharging, over-discharging, and short circuits. Similarly, the use of fuses will not impact the overall power consumption, as fuses are passive components that only interrupt the circuit when the current exceeds the specified limit. Under normal operating conditions, both the BMS and fuses function as safety mechanisms without drawing significant power.

Formula for Operating Time Based on Load Conditions:
T_operation = E_battery / [(f_heavy × P_heavy) + (f_normal × P_normal)]

Variables Explained:

T_operation: Total operating time of the robot (in hours).

E_battery: Energy stored in the battery, in watt-hours (Wh).

- Example: For a 3Ah, 3.7V LiPo battery, E_battery = 11.1Wh.

f_heavy: Fraction of time the robot spends under heavy load (as a decimal).

- Example: If the robot operates under heavy load 10% of the time, f_heavy = 0.1.

P_heavy: Power consumption during heavy load (in watts, W).

- Example: P_heavy = 13.05W (including motor and other components).

f_normal: Fraction of time the robot spends under normal load (as a decimal).

- Example: If the robot operates under normal conditions 90% of the time, f_normal = 0.9.

P_normal: Power consumption during normal load (in watts, W).

- Example: P_normal = 4.17W (including motor and other components).

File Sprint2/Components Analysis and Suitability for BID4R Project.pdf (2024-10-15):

# Component Analysis and Suitability for BID4R Project

Mohammed Alasmari

EE 421

October 2024

1- Mini 3-Layer Round Robot Chassis Kit - 2WD with DC Motors

- Main Specifications:
- Drive Motors Voltage: 3-6V DC.
- Current Draw: 200-400mA (normal), 1.5A (stall).
- Material: Aluminum alloy chassis.
- Responsibility:

The chassis provides the physical structure and mobility for the robot. The two DC motors attached to the wheels are responsible for movement, allowing the robot to drive forward, backward, and turn.

- Suitability:

The chassis is lightweight, providing enough space for mounting all components and wiring. The motors' voltage range of 3-6V allows them to be powered directly by the 3.7V LiPo battery, though they will operate with lower performance compared to 6V. The motors' current draw is manageable, but the stall current of 1.5A requires protection (fuses).

- Considerations:

The stall current could damage the motor driver if not limited.

- Solution:

Install 1.5A fuses in series with the motors to prevent overcurrent from damaging the driver and the system.
2- Adafruit DRV8833 DC/Stepper Motor Driver Breakout Board
- Main Specifications:
- Voltage Range: 2.7V to 10.8V.
- Continuous Current: 1.2A per channel (2A peak).
- Responsibility: The motor driver acts as the interface between the Arduino and the motors. It translates the PWM control signals from the Arduino into power for the motors, allowing for precise control of speed and direction.

- Suitability: The motor driver is well-suited to control the robot’s DC motors, as it supports a wide voltage range (compatible with the 3.7V battery). However, it can only handle 1.2A continuously, which means it’s close to its limit during stall conditions. This makes the use of fuses essential.
- Considerations: The driver must not exceed its current rating, especially during motor stall conditions.
- Solution: Use 1.5A fuses to protect the motor driver and consider adding heat sinks to manage heat under heavy loads.
3- Arduino Nano 33 IoT
- Main Specifications:
- Operating Voltage: 3.3V (logic), 5V via VIN for power.
- Processor: ARM Cortex-M0+ SAMD21.
- Responsibility: The Arduino Nano 33 IoT is the brain of the robot. It processes sensor inputs, executes decision-making logic, and sends control signals to the motor driver to manage the robot’s movement. It also handles wireless communication via Wi-Fi and Bluetooth if needed.
- Suitability: The Arduino Nano is perfectly suited for this project because of its small form factor and low power consumption, making it ideal for battery-powered robots. It operates on 3.3V logic, which is compatible with the sensors. The PowerBoost 1000C can provide the necessary 5V to power the Arduino through the VIN pin.
- Considerations: Ensure that the sensors connected to the Arduino are compatible with its 3.3V logic.
4- Pixy2 Smart Vision Sensor
- Main Specifications:
- Power Supply: 5V.
- I2C Logic Level: 3.3V I2C logic.
- Responsibility: The Pixy2 sensor provides the robot with vision capabilities, such as object and color detection, which can be used to guide the robot’s movement (e.g., following a line or tracking a specific object).

- Suitability: The Pixy2 sensor is highly suitable for the project due to its ability to communicate using 3.3V I2C logic, making it compatible with the Arduino Nano 33 IoT without requiring an I2C level shifter. The 5V power requirement can easily be supplied by the PowerBoost.
- Considerations: No level shifter is needed as the sensor communicates using 3.3V logic.

5- Universal Qi Wireless Receiver Module

- Main Specifications:
- Output Voltage: 5V.
- Output Current: 1A max.
- Responsibility: This module enables the robot to charge wirelessly by receiving power from the wireless charging transmitter. It converts the received energy into 5V to charge the LiPo battery via the PowerBoost 1000C.
- Suitability: The Qi receiver module is well-suited for enabling autonomous charging without the need for physical connectors, providing the necessary 5V to charge the battery.
- Considerations: Proper alignment between the receiver and transmitter is essential for efficient charging.
6- Universal Qi Wireless Charging Transmitter
- Main Specifications:
- Input Voltage: 5V (typically via USB).
- Output Power: 5W.
- Responsibility: The transmitter is responsible for wirelessly providing power to the Qi receiver, enabling the robot to recharge its battery without manual intervention.
- Suitability: The transmitter works seamlessly with the Qi receiver to provide power for charging the robot’s battery. It ensures the robot can charge autonomously when placed on the charging pad.
- Considerations: Ensure that the charging station is designed for proper alignment between the transmitter and receiver.
7- 4x 3.7V Lithium LiPo Battery (3000mAh)

- Main Specifications:
- Voltage: 3.7V.
- Capacity: 3000mAh.
- Responsibility: The battery provides the main power supply for the motors, Arduino, and sensors, by supplying 3.7V to the PowerBoost 1000C, which converts it to 5V.
- Suitability: The battery has a high enough capacity (3000mAh) to power the system for an extended period. It can also handle the current demands of the motors and other components. The PowerBoost converts the battery’s 3.7V to the required 5V for the Arduino and other components, making it well-suited for the robot.
- Considerations: A BMS (Battery Management System) is essential to protect the battery from over-discharge, overcharge, and short circuits.

8- VCNL4010 Proximity/Light Sensor

- Main Specifications:
- Power Supply: 3.3V to 5V.
- I2C Logic Level: 3.3V to 5V compatible.
- Responsibility: The proximity sensor provides environmental feedback by detecting obstacles, enabling the robot to avoid collisions. It also measures ambient light, allowing for light-based decisions.
- Suitability: The sensor is compatible with the 3.3V I2C logic of the Arduino Nano 33 IoT, making it easy to integrate without a level shifter. Its low power requirements make it ideal for use in battery-powered robots.
- Considerations: Ensure proper placement for effective obstacle detection.

9- PowerBoost 1000C

- Main Specifications:
- Input Voltage: 3.7V (from LiPo battery).
- Output Voltage: 5V.
- Output Current: 1A continuous.

- Responsibility: The PowerBoost 1000C is responsible for converting the 3.7V output from the LiPo battery into a stable 5V supply to power the Arduino Nano 33 IoT, sensors, and other 5V components.
- Suitability: The PowerBoost 1000C is perfectly suited for this project as it provides a continuous 1A at 5V, which is sufficient for powering the entire system. The total current draw of the components (including sensors, camera, and Arduino) does not exceed the 1A limit, ensuring safe and efficient operation.
- Considerations: Ensure the total current draw remains within the 1A limit and consider spreading the load or using an additional PowerBoost if future
components increase the current requirements.
10- APA106 LEDs (Addressable RGB LEDs)
- Main Specifications:
- Power Supply: 5V.
- Current Draw: 20mA per LED.
- Responsibility: Provides visual feedback for the robot, useful for signaling or status indication.
- Suitability: The PowerBoost 1000C provides 5V for powering the LEDs.
- Considerations: If you use 50 LEDs, the total current draw will reach 1A, leaving no room for other components.
- Solution: Limit the number of LEDs or use an additional power supply if more LEDs are needed.
11- Resistors
- Main Specifications:
- Resistance Value: 330Ω for APA106 LEDs.
- Power Rating: 1/4W.
- Responsibility: Regulates the current flow to the LEDs, preventing damage from voltage spikes.
- Suitability: The 330Ω resistor is suitable for protecting the APA106 LEDs' data line.
- Considerations: Place a 330Ω resistor on the data line of the first LED to prevent damage.

Final Considerations and Solutions:

Compon ent | Responsibili ty | Solution | Quantity | Links
Fuses (1.5A) | Protects motors and motor driver from overcurrent. | Use fuses to prevent overcurrent from damaging the motors and driver. | 2 | https://www.amazon.com/1-5AMP-10PCS-LITTELFUSE-31301-5-DELAY/dp/B0CCWRK Q3B (https://www.amazon.com/1-5AMP-10PCS-LITTELFUSE-31301-5-DELAY/dp/B0CCWRKQ3B)
BMS | Protects LiPo battery from overcharging /discharging. | A BMS is essential for safe battery management and ensuring battery health. | 1 | https://a.co/d/dhIeBX 8 (https://a.co/d/dhIeBX8)

# The Additional Component Analysis and Suitability for BID4R Project

12- Littelfuse 1.5A Slow-Blow Fuse (31301.5)

- Main Specifications:
- Current Rating: 1.5A.
- Type: Slow-blow (time delay).
- Voltage Rating: 250V.
- Dimensions: 5mm x 20mm.
- Responsibility: The Littelfuse 1.5A slow-blow fuse is responsible for protecting the motors and the motor driver from overcurrent by interrupting the circuit if the current exceeds 1.5A for an extended period. This fuse type can tolerate brief current surges (such as motor startups) but will blow if a motor stalls and continuously draws a high current.
- Suitability: This fuse is well-suited for the setup because:

- The motors in the Mini 3-Layer Round Robot Chassis Kit have a stall current of 1.5A, making the 1.5A fuse ideal for protecting them.
- The DRV8833 motor driver provides 1.2A continuously, so the fuse ensures that if the motors draw more than 1.5A (due to stalling), the circuit will break, protecting the motor driver from damage.
- The slow-blow characteristic ensures that the fuse will not blow immediately during short surges (like motor startup), which momentarily increases the current.
- Considerations:
- In this setup, the fuses should be installed between the motor driver and each motor. This way, if one motor stalls and draws too much current, only the fuse for that motor will blow, while protecting the motor driver and other motor from overcurrent.
- Ensure the physical size of the fuse (5mm x 20mm) is appropriate for the setup and that you use a compatible fuse holder if necessary.

13- 1S 3.7V LiPo BMS Protection Module (5A)

Main Specifications:

- Battery Type: Single-cell 3.7V LiPo battery.
- Max Current: 5A.

Responsibility:

The 1S 3.7V LiPo BMS Protection Module is responsible for managing and protecting the LiPo battery used in the system. It ensures the battery is operated safely by preventing overcharging, over-discharging, and short circuits. It also cuts off power if the current drawn exceeds 5A, thus protecting the battery and other connected components like the motors and controllers.

Suitability:

This BMS is well-suited for the setup because:

- It matches the 1S (single-cell) LiPo battery configuration of 3.7V, which is commonly used in smaller robots and portable devices.
- The 5A current rating ensures protection for low-current applications like controlling small motors or powering the Arduino module.

- The module provides key protections (overcharge, over-discharge, short circuit) to ensure safe battery usage and extend battery life, making it suitable for projects with limited power requirements.

Considerations:

- Ensure the BMS is installed correctly between the battery and the load (e.g., PowerBoost or motor driver), with battery leads connected directly to the LiPo cell and output leads going to the load.
- Ensure the system’s current draw does not exceed the 5A limit, as this could cause the BMS to cut off power unexpectedly.

References

[1] "Utilizing Fuses for Overcurrent Protection," eepower.com, [Online]. Available: https://eepower.com/technical-articles/utilizing-fuses-for-overcurrent-protection/. (https://eepower.com/technical-articles/utilizing-fuses-for-overcurrent-protection/) [Accessed: 12-Oct-2024].
[2] D. Andrea, "Battery Management System for Overcharge Protection," Applied Sciences, vol. 7, no. 12, p. 1314, 2017. [Online]. Available: https://www.mdpi.com/2076-3417/7/12/1314. [Accessed: 12-Oct-2024].
[3] "Overcharging Lithium-ion Polymer Batteries," Grepow.com, [Online]. Available: https://www.grepow.com/blog/overcharging-lithium-ion-polymer-batteries.html. (https://www.grepow.com/blog/overcharging-lithium-ion-polymer-batteries.html) [Accessed: 12-Oct-2024].

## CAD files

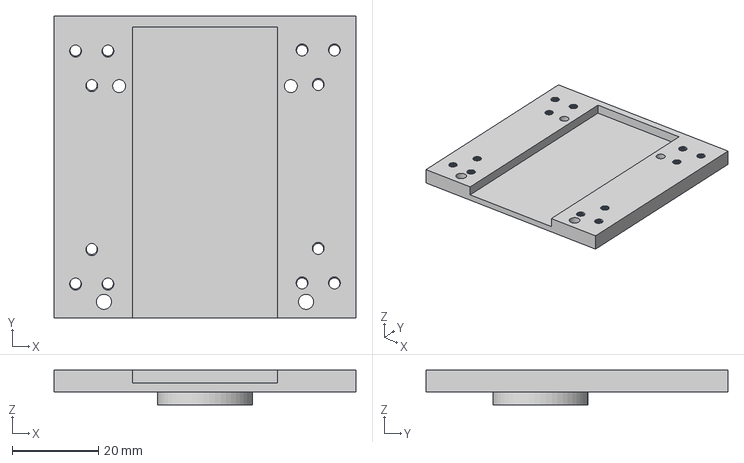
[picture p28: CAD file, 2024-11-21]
Charging_Station_Documentation/CAD_files/Chassis (22mm).step
70.0 x 70.0 x 8.00 mm

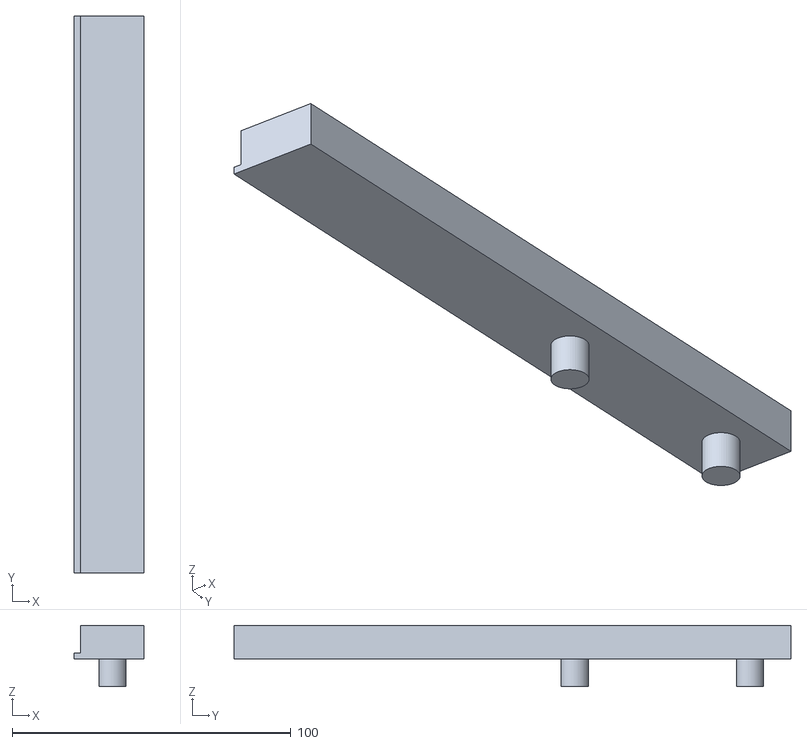
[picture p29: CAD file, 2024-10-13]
Sprint2/Charging_Station/stl_files/Body13.stl
25.0 x 200.0 x 22.0

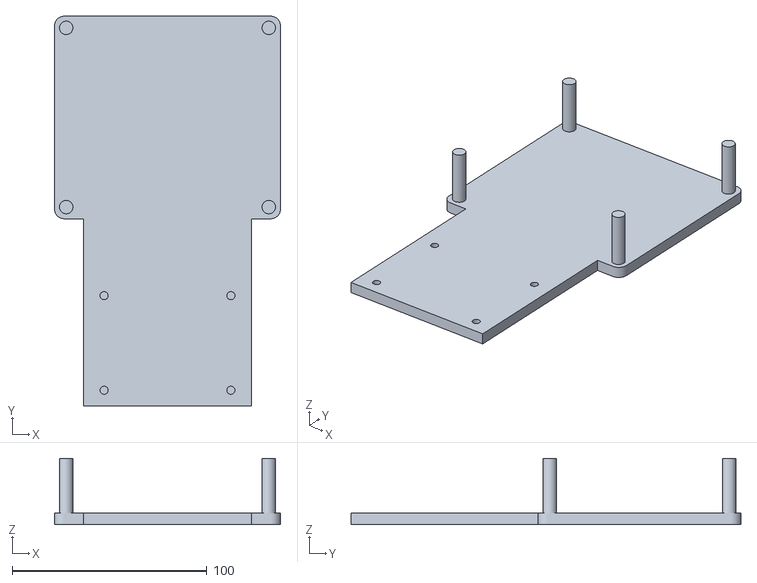
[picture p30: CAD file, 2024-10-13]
Sprint2/Charging_Station/stl_files/Body3.stl
116.0 x 200.0 x 34.0

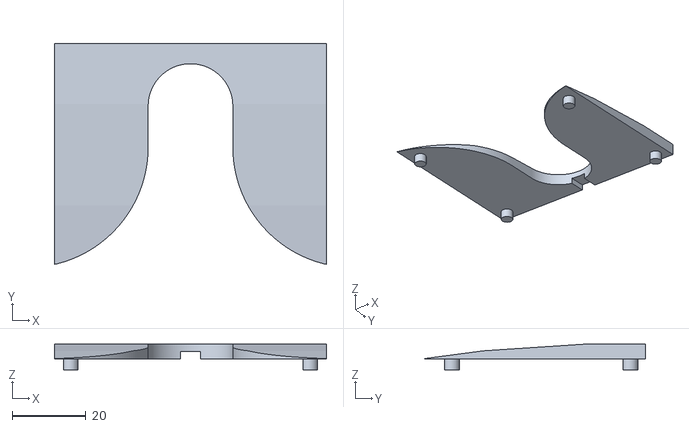
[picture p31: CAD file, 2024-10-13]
Sprint2/Charging_Station/stl_files/Body4.stl
74.0 x 60.1 x 7.00

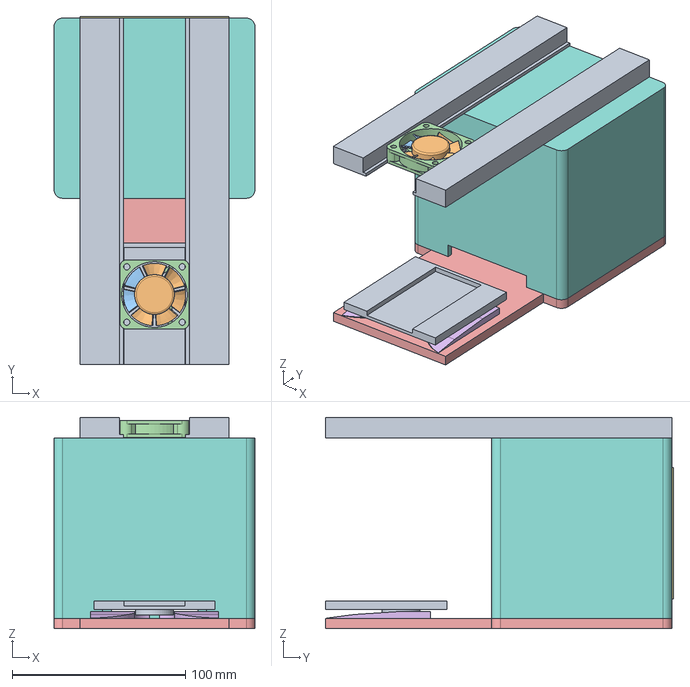
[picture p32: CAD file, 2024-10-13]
Sprint2/Charging_Station/stl_files/Robo Base V3 v1.step
116.0 x 201.0 x 122.0 mm
Chassis V2 v1
1939K17_Low-Voltage Equipment-Cooling Fan

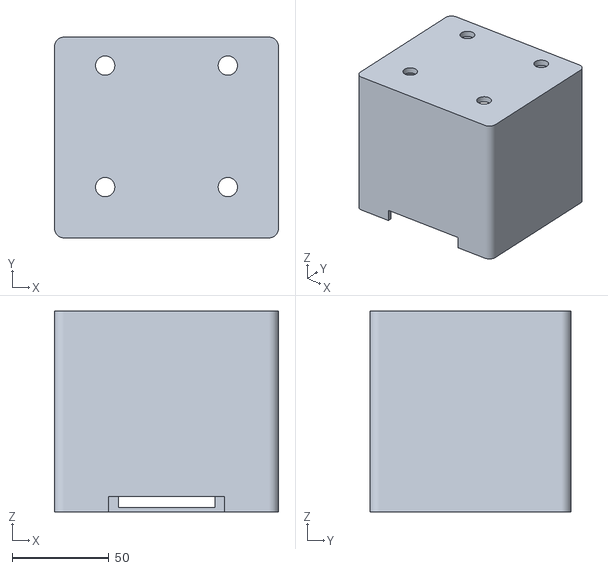
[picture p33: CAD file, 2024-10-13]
Sprint2/Charging_Station/stl_files/Body10.stl
116.0 x 104.0 x 104.0

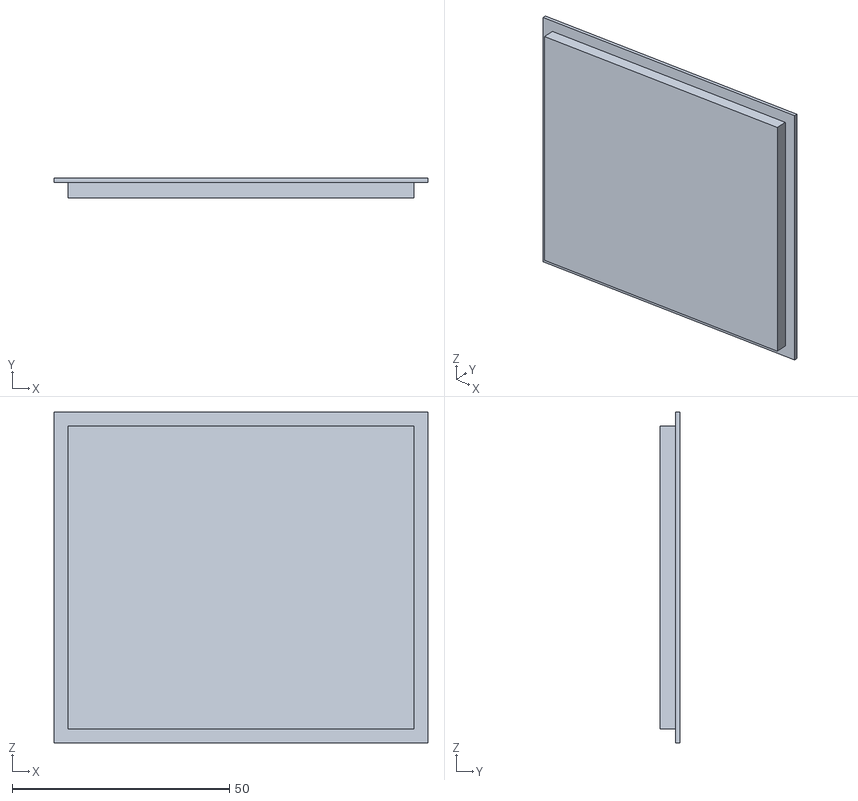
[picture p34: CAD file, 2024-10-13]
Sprint2/Charging_Station/stl_files/Body8.stl
86.0 x 4.50 x 76.0

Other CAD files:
Charging_Station_Documentation/CAD_files/Chassis (45mm).step
Sprint2/Charging_Station/stl_files/Body12.stl
Sprint2/Charging_Station/stl_files/Chassis V2 with Screw Holes.stl

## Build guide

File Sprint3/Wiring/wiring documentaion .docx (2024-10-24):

Wiring Documentation for Arduino-Controlled Robot System

1. System Overview:

This wiring documentation covers the connections for a robot system controlled by an Arduino Nano 33 IoT, integrated with various sensors, motors, a camera, and a power management system. The primary objective is to manage the power distribution, motor control, sensor integration, and provide real-time status through LED indicators, while ensuring safe battery management using a PowerBoost 1000C and Qi wireless charging.

2. Components and Connections:

2.1. Arduino Nano 33 IoT:

- Power Source (5V): Powered by the PowerBoost 1000C.
- GND: Common ground shared with all components.

Digital Pins:

- D0/D1 (TX/RX): Connected to the Pixy2 camera for serial communication.
- D2: Connected to the DS18B20 temperature sensor data line.
- D3 to D6: Used to control the motor controller's direction (AIN1, AIN2, BIN1, BIN2) for the two DC motors.
- D7: Used to monitor the Low Battery Output (LBO) from the PowerBoost, signaling when the battery is critically low.
- D8: Connected to the APA106 RGB LED to display battery levels or charging status.
- D9: Controls the relay, allowing or preventing charging based on temperature and other conditions.

Analog Pins:

- A0: Connected to a voltage divider for continuous battery voltage monitoring.
- A4/A5 (I2C SDA/SCL): Used for the proximity sensor (Adafruit #466) to measure distances and obstacles.

2.2. PowerBoost 1000C:

- BAT Pin: Connected directly to the LiPo battery's positive terminal. This pin reads the voltage from the battery and steps it up to 5V for the system.
- 5V Output: Powers the Arduino Nano 33 IoT and other 5V components, such as the Pixy2 camera and LEDs.
- GND: The ground pin is connected to the common ground of the entire system.
- LBO Pin: Connects to D7 on the Arduino to signal when the battery drops below 3.2V, ensuring that critical low-battery conditions can be handled appropriately.

2.3. LiPo Battery (3.7V, 3000mAh):

- Positive Terminal: Connected to the BAT pin on the PowerBoost.
- Negative Terminal: Connected to the common ground, shared across all components in the circuit.

2.4. DS18B20 Temperature Sensor:

- VDD: Connected to the 3.3V output of the Arduino Nano.
- GND: Connected to the common ground.
- DQ Pin: Connects to D2 on the Arduino for temperature data communication.

2.5. Pixy2 Camera:

- TX/RX Pins:
  - TX Pin connected to D0 (RX on the Arduino Nano).
  - RX Pin connected to D1 (TX on the Arduino Nano).
- 5V Input: Connected to the 5V output from the PowerBoost to power the camera.
- GND: Connected to the common ground.

2.6. Qi Receiver:

- Connected through Relay: The Qi receiver’s output is connected to the relay’s NO (Normally Open) terminal to control the charging circuit.
- GND: Common ground with the system.
- Relay Control: The relay is controlled by the Arduino to start/stop charging based on temperature and other conditions.

2.7. Relay (Adafruit Power Relay FeatherWing):

- COM (Common): Connected to the positive terminal of the Qi receiver.
- NO (Normally Open): Connected to the LiPo battery via the PowerBoost.
- Relay Control Pin (D9): Controlled by the Arduino to open or close the circuit depending on the system's conditions (temperature, low battery).

2.8. APA106 RGB LED:

- DIN: Data input connected to D8 of the Arduino to display different colors based on the battery charge status.
- VDD: Connected to the 5V output from the PowerBoost.
- GND: Connected to the common ground.

2.9. Proximity Sensor (Adafruit #466):

- SDA (A4): Connected to the Arduino's I2C SDA pin for communication.
- SCL (A5): Connected to the Arduino's I2C SCL pin for communication.
- GND: Connected to the common ground.
- VDD: Connected to the 3.3V pin from the Arduino.

2.10. Motor Controller (Adafruit DRV8833):

- AIN1 (D3) and AIN2 (D4): Control motor A (first motor) for direction.
- BIN1 (D5) and BIN2 (D6): Control motor B (second motor) for direction.
- VMOT: Connected directly to the LiPo battery’s positive terminal to supply power to the motors.
- GND: Connected to the common ground.

2.11. Motors:

- Connected to the Motor Controller: The two DC motors are connected to the AOUT1, AOUT2, BOUT1, and BOUT2 of the motor controller, allowing control of the direction and speed of both motors.

3. Voltage Divider for Battery Monitoring:

- R1 (10KΩ): Connected between the BAT pin of the PowerBoost and A0 on the Arduino.
- R2 (20KΩ): Connected between A0 and GND. This reduces the battery voltage to a level that can be safely read by the Arduino for continuous monitoring of the battery state.

4. Power and Grounding Scheme:

- Common Ground: All components share a common ground, which is connected to both the PowerBoost 1000Cand the LiPo battery’s negative terminal.
- 5V Distribution: The PowerBoost 1000C outputs 5V to power the Arduino and 5V components (e.g., the Pixy2 camera and RGB LED).

5. Software Integration:

The Arduino code manages:

1. Battery Monitoring: Through the LBO pin and voltage divider, the Arduino monitors battery status and controls power management.
2. Temperature Control: Reads the temperature from the DS18B20 and stops charging when the temperature exceeds the threshold (e.g., 45°C).
3. Proximity and Camera Systems: Manages sensor data and communicates with the Pixy2 camera for object detection.
4. Motor Control: Uses the motor controller to drive the two DC motors in response to sensor inputs and commands.

Conclusion:

This system integrates multiple components for robust control of a robot platform, including safe battery management via the PowerBoost 1000C and Qi charging, temperature monitoring, and proximity sensing. The wiring ensures efficient power distribution, safe sensor operation, and motor control, with real-time feedback provided by an RGB LED for status indication.

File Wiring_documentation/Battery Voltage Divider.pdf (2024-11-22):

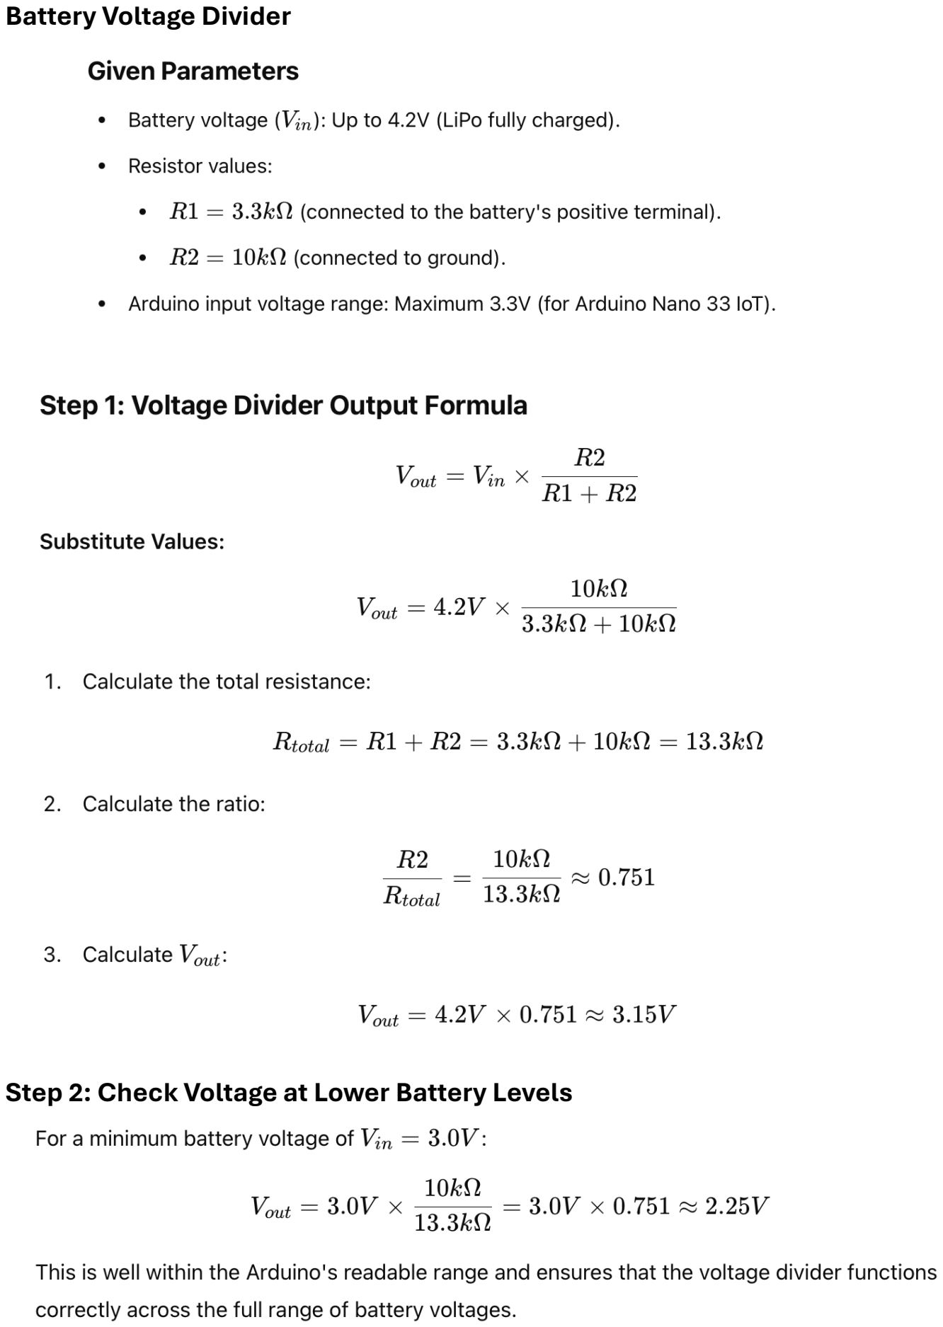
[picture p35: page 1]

Battery Voltage Divider

Step 2: Check Voltage at Lower Battery Levels

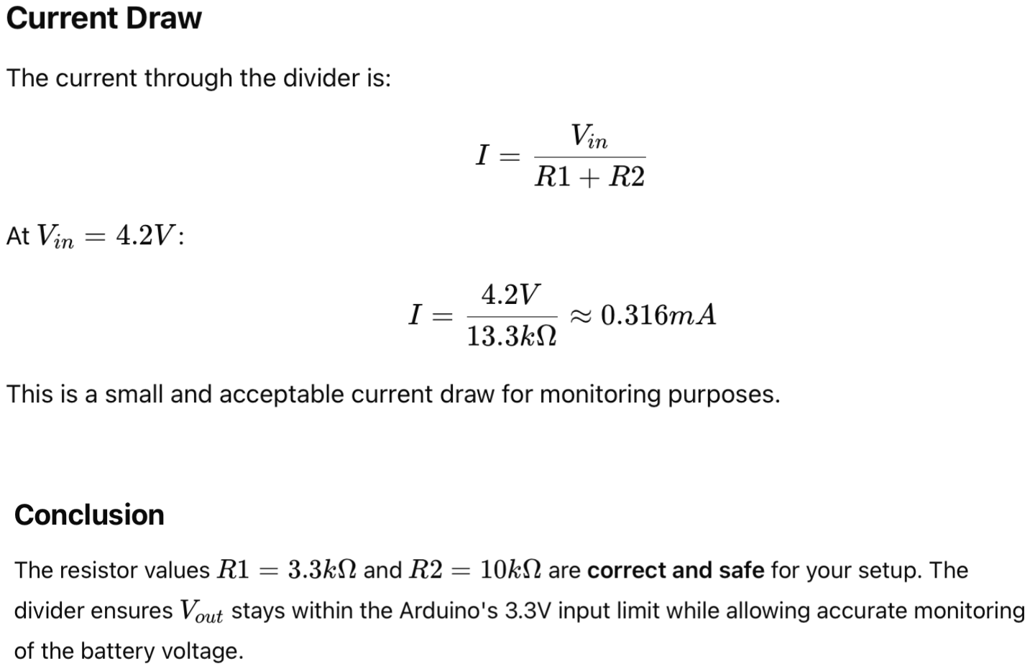
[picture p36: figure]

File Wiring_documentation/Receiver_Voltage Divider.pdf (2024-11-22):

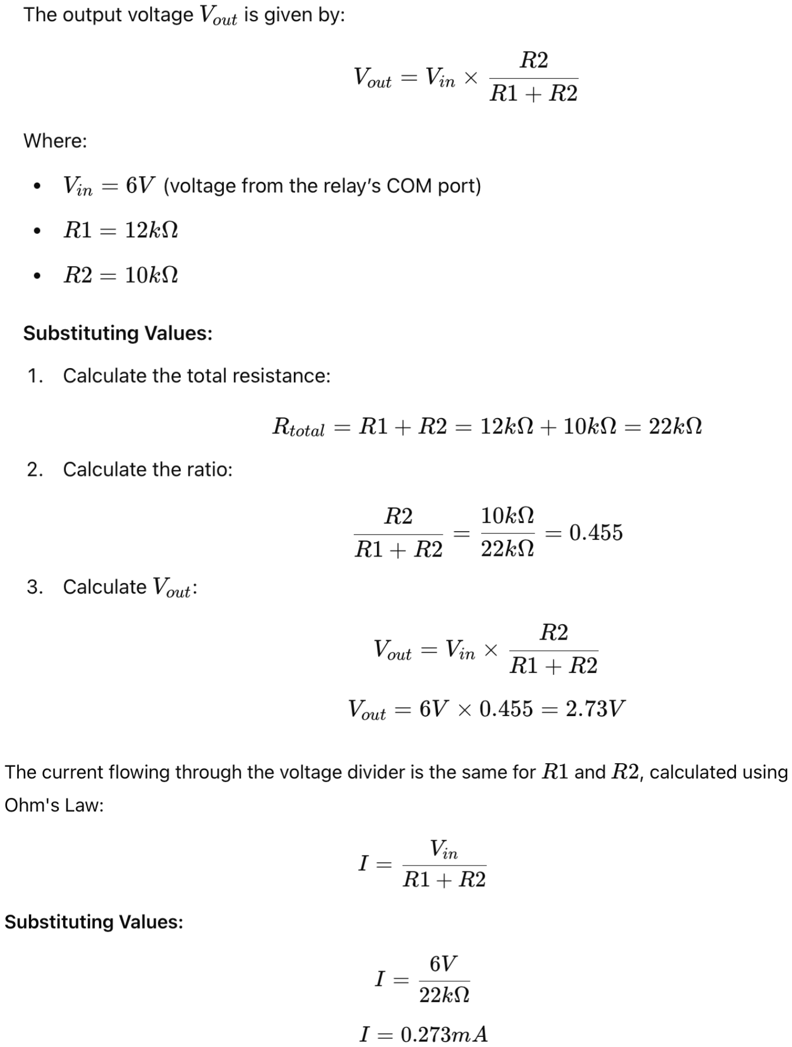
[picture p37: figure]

Calculations

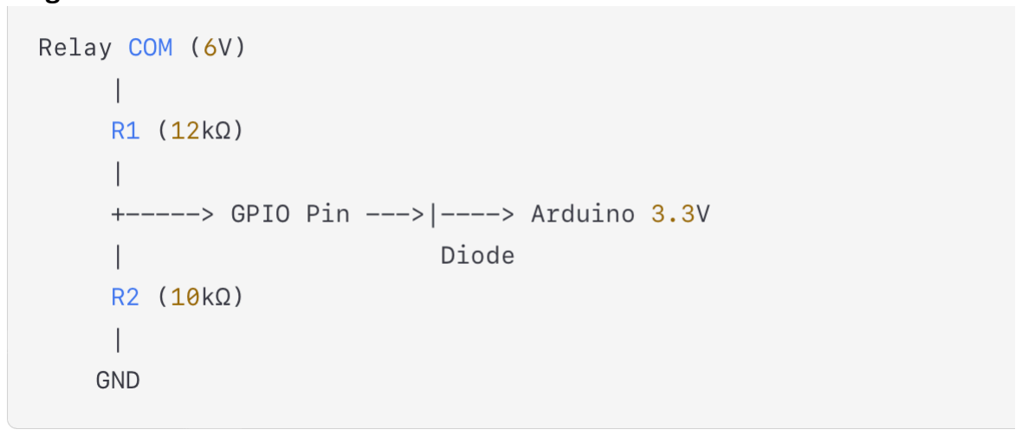
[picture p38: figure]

Wiring

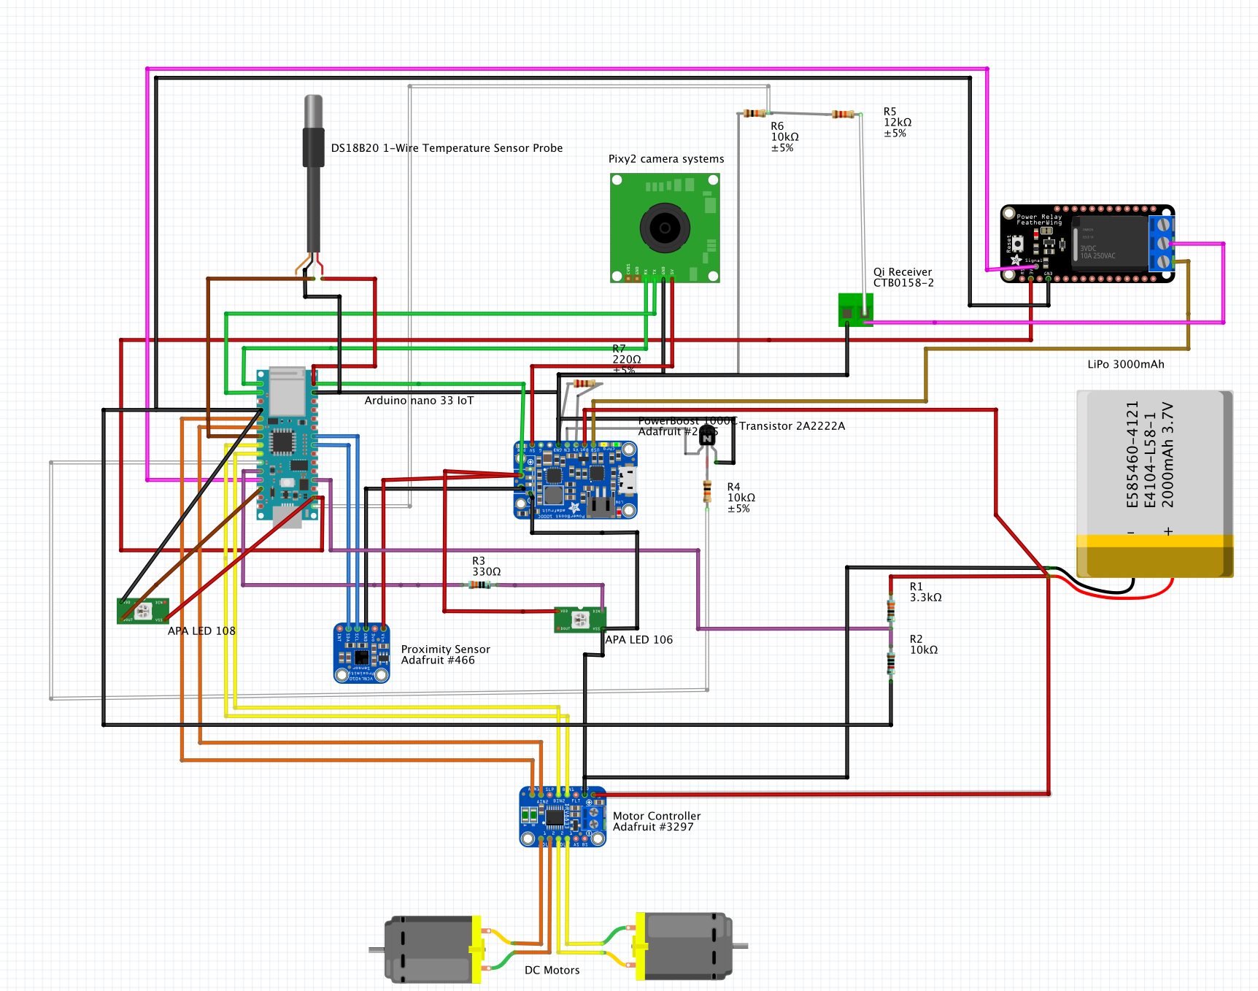
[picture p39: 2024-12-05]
Wiring_documentation/final wiring.png

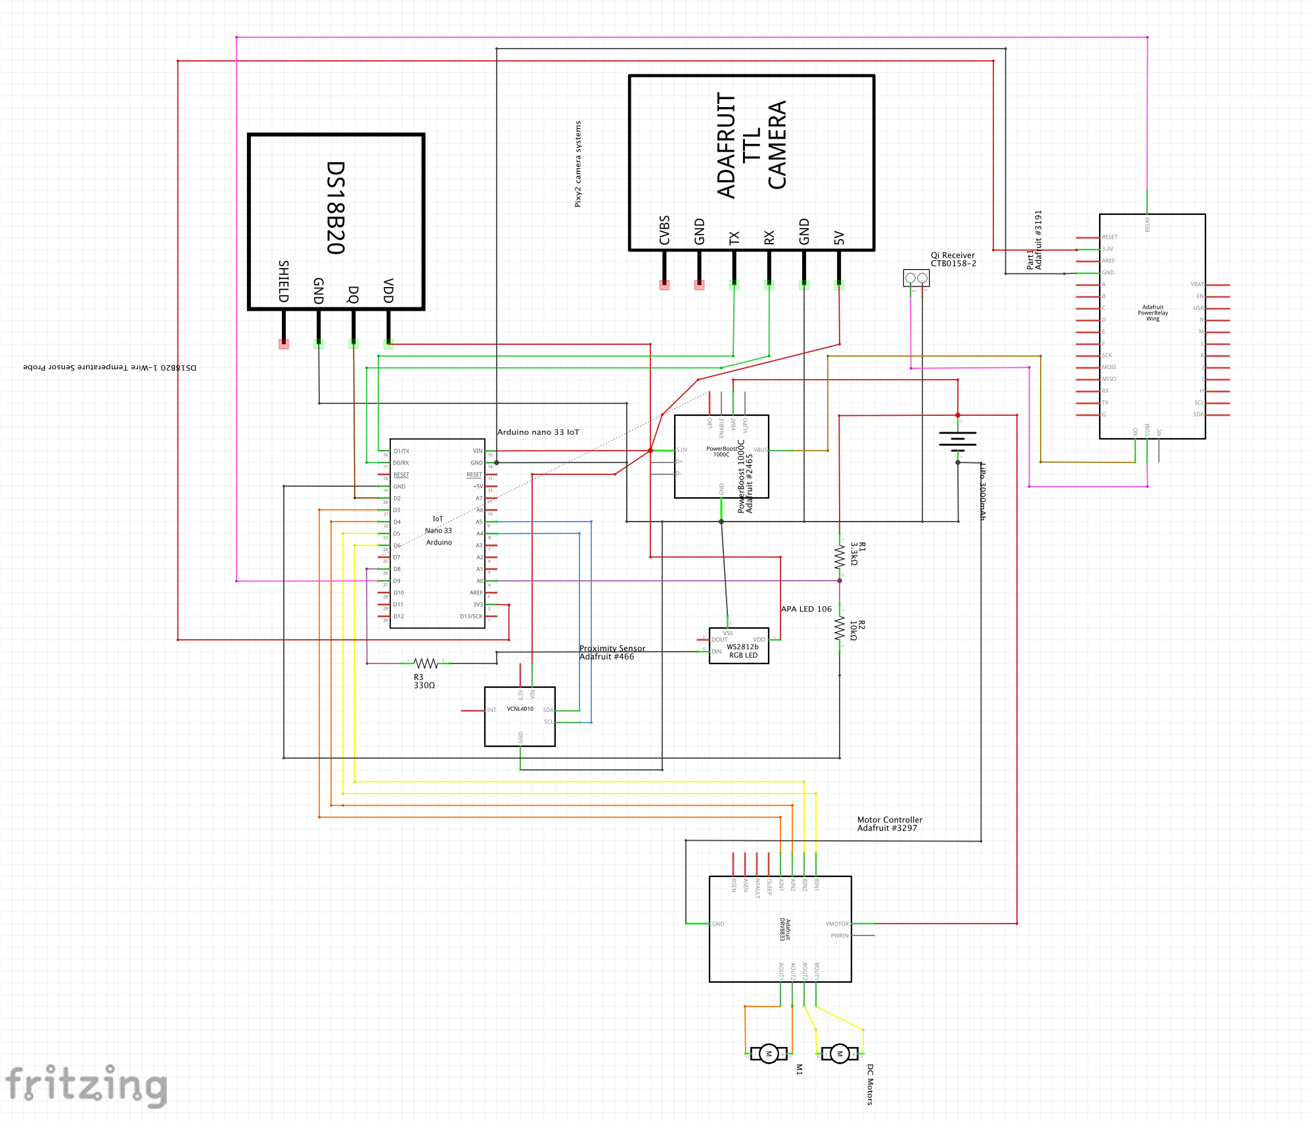
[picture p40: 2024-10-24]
Sprint3/Wiring/Wiring_Digram_schematic.png

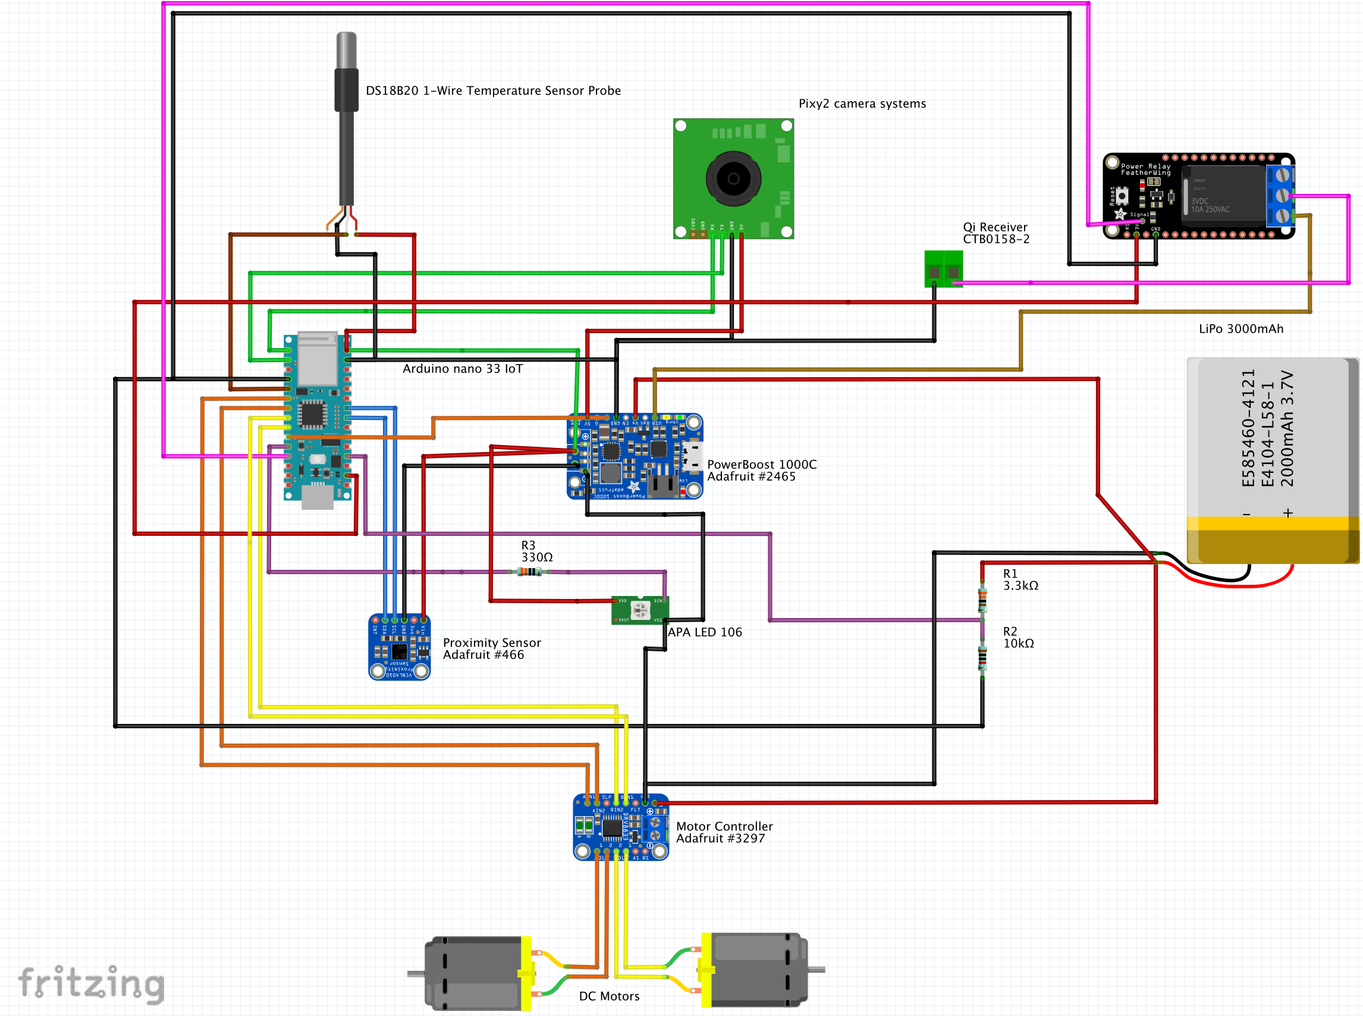
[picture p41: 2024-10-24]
Sprint3/Wiring/Wiring_Digram.png

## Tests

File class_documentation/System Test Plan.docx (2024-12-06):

BID4R

System Test Plan

Version <1.0>

12/5/2024

# Document Control

The following list of people will receive a copy of this document every time a new version of this document becomes available:

Teaching assistants:

Luke Newcomb

Customer(s):

Dr. Bryan Watson

Project team members:

Turki Alturki

Mohammed Alasmari

Belal Abed

Change Summary

The following table details changes made between versions of this document:

Version | Date | Modifier | Description
1.0 | 11/24/2024 | Belal | Initial creation- Introduction
1.0 | 11/24/2024 | Mohammed | Testing Approach-Usability Testing
1.0 | 11/24/2024 | Turki | Testing Approach-Functionality Testing
1.0 | 11/25/2024 | Mohammed | Testing Approach -Testing Environment
1.0 | 11/25/2024 | Turki | Testing Approach -Testing Assumptions
1.0 | 11/27/2024 | Mohammed | Testing Approach -Testing Risks and Contingencies
1.0 | 11/28/2024 | Belal | Testing Approach -Test Plan
1.0 | 12/2/2024 | Belal | Test Schedule
1.0 | 12/4/2024 | Turki | Test Cases
1.0 | 12/5/2024 | Mohammed, Belal, Turki | Final revision

Table of Contents

# 1. Introduction

This System Test Plan outlines the testing process for the rover system. It includes test cases and methodologies to verify the system's functionalities, including charging, battery monitoring, and temperature management, ensuring reliable operation under various conditions. The plan is designed to ensure that all components function as expected in normal and edge-case scenarios.

## Purpose

The purpose of this document is to define the testing approach, methods, and criteria for validating the functionalities of the rover system. It contains detailed test cases, a traceability matrix, and defect severity classifications to ensure comprehensive coverage of the system’s capabilities.

## Scope

This test plan covers all functionalities of the rover system, focusing on critical areas such as:

1. Wireless Charging: Ensuring proper alignment and current handling capabilities.
2. Battery Monitoring: Providing accurate real-time voltage levels during operation and charging.
3. Temperature Monitoring: Detecting overheating and issuing alerts while maintaining safe operational parameters.
4. LED Indicators: Providing clear feedback on the system's status under different operational conditions.

This plan applies to the current hardware and software versions of the rover system.

## System Overview

The rover system is designed to operate as an autonomous platform with integrated functionalities for wireless charging, battery monitoring, temperature sensing, and feedback through LED indicators. The testing approach focuses on validating these functionalities to ensure the system operates reliably in various scenarios.

## Testing Approach Overview

The testing approach focuses on validating functional, usability, and performance aspects of the rover system:

- Functional Testing: Verifying individual modules (e.g., charging, monitoring, and LED feedback).
- Stress Testing: Evaluating the system's behavior under edge conditions, such as low battery or overheating.
- Integration Testing: Ensuring modules interact seamlessly (e.g., accurate LED feedback during charging).
- Regression Testing: Validating that resolved issues remain fixed after updates.

Each test is executed based on predefined test cases, ensuring measurable and consistent outcomes.

## References

This section lists the key references and resources consulted during the development of the BID4R project. These references provide background information, technical specifications, and industry standards relevant to the design and implementation of the wireless charging and battery integration solution.

1. Arduino Nano IoT Documentation – Technical documentation for the Arduino Nano IoT, including pin configurations, power limitations, and programming guidelines essential for the control system of the BID4R project.

Link: https://github.com/turkia1/BID4R/blob/main/Wiring_documentation/Component_Documentation/ABX00027-datasheet.pdf

2. Adafruit PowerBoost 1000C Documentation – Specifications and usage information for the PowerBoost 1000C module, including voltage conversion and output capabilities that enable efficient energy transfer from the Qi receiver to the LiPo battery.

Link: https://github.com/turkia1/BID4R/blob/main/Wiring_documentation/Component_Documentation/adafruit-powerboost-1000c-load-share-usb-charge-boost.pdf

3. 3D Design and CAD Files for Charging Station – CAD files and design guidelines used to model the physical structure of the wireless charging station, with specific features for alignment and thermal management.

Link:

https://github.com/turkia1/BID4R/tree/main/Charging_Station_Documentation

4. Wiring and Circuit Design References – Fritzing diagrams and wiring guidelines, used to assemble and validate the connectivity of electronic components, ensuring correct voltage levels, ground connections, and data flow between modules.

Link:

https://github.com/turkia1/BID4R/tree/main/Wiring_documentation

5. Project Requirements Document – A prior document detailing the functional and non-functional requirements of the BID4R project, which provided a foundation for the system design and identified specific operator needs.

Link:

https://github.com/turkia1/BID4R/blob/main/class_documentation/SRSv1.docx

6. Components Analysis for BID4R Project – Analysis report on component suitability and performance metrics, including the choice of sensors, LEDs, and connectors necessary for the seamless operation of the BID4R system.

Link:

https://github.com/turkia1/BID4R/blob/main/Sprint2/Components%20Analysis%20and%20Suitability%20for%20BID4R%20Project.pdf

7. LiPo Battery Safety Regulations -A Comprehensive guidelines on LiPo battery safety standards and implementation of

Qi wireless charging, focusing on safety protocols and regulatory compliance.

Link:

https://github.com/turkia1/BID4R/blob/main/Sprint2/LiPo_regulation.PDF

These references serve as foundational resources for understanding the technologies, safety protocols, and design considerations applied in this project. They provide essential information for the development team and stakeholders to understand the scope, constraints, and technical direction of the BID4R project.

# 2. Testing Approach

This testing approach outlines the plan to validate the rover system's components and functionality. It includes functional, usability, and stress tests designed to exercise system functions individually and in integrated scenarios. Additionally, it ensures the system meets operational requirements under normal and edge-case conditions.

### Usability Testing

User interface attributes, particularly the LED feedback system, will be tested for clarity and usability. The objective of this test is to ensure that the system provides the user with consistent and appropriate feedback during charging, battery monitoring, and operational states. Usability testing focuses on the following:

- Clear and distinct LED patterns for each status condition (charging, battery levels, overheating).
- Proper transition between LED statuses as system conditions change.

### Functionality Testing

Functionality tests ensure that each system component meets its respective requirements. These include:

- Wireless Charging Module: Verify proper alignment and current handling capabilities.
- Battery Monitoring System: Validate accurate real-time voltage readings during operation and charging.
- Temperature Monitoring Module: Ensure reliable detection of overheating and issuance of alerts.
- LED Feedback System: Confirm accurate LED indicators for system states.

Each of these tests corresponds to the test cases outlined in Section

## Testing Suspension Criteria and Resumption Requirements

Stress tests evaluate the system's behavior under extreme conditions to ensure robustness. These include:

- Operating with low battery levels (e.g., below 10% or 3.3V).
- Simulating overheating scenarios (> 45°C).
- Charging with high loads and alignment disruptions.

### Suspension Criteria

Testing will be suspended if:

- Critical defects are discovered that prevent further testing, such as failure to detect battery voltage or overheating.
- Hardware malfunctions, such as the Qi wireless charging module or temperature sensor failure.
- Testing equipment (e.g., Arduino, multimeter) becomes inoperable.

If testing is suspended, the Testing Manager will assess the situation and determine whether the test plan needs to be partially or fully re-executed after the issue is resolved.

### Resumption Requirements

Testing will resume when:

- The functionality that caused the suspension is verified to be operational.
- Hardware, software, or database fixes have been successfully implemented and validated.
- Required testing tools and configurations are restored to operational status

## Testing Environment

The testing environment includes the following:

- Hardware:
  - Qi wireless charging modules.
  - Battery (3.2V–4.2V range).
  - Arduino microcontroller with USB connection.
  - Temperature sensor.
  - Multimeter for voltage and current measurements.
- Software:
  - Arduino IDE for monitoring serial output.
  - Custom firmware for battery voltage and temperature monitoring.
- Configuration:
  - Rover powered through the battery for normal operation tests.
  - Arduino powered through USB to avoid dual-power issues.

Tests will be executed in a controlled lab environment with a stable ambient temperature unless simulating overheating.

## Testing Assumptions

The following assumptions are made:

- The battery and sensors meet their specification tolerances.
- Testing equipment is calibrated and functional.
- All components are integrated correctly before testing begins.
- The Qi wireless charging modules operate within their rated capacity.

## Testing Risks and Contingencies

Overheating Risk: Extended charging or high loads may cause overheating.

- Mitigation: Limit testing durations and monitor temperature closely.

Alignment Failures: Misalignment of the Qi wireless charging module may result in failure to charge.

- Mitigation: Ensure proper alignment during tests and note alignment tolerances.

Sensor Failures: Voltage or temperature sensors may produce inaccurate readings.

- Mitigation: Cross-validate readings with external tools such as a multimeter.

Dual Power Conflict: Arduino powered by both USB and battery simultaneously may cause damage.

- Mitigation: Use protective circuitry, such as diodes, to isolate power sources.

## Test Plan

The test plan includes test cases for the two primary states of the robot: Charging State and Normal Operation State. Each test case is named to reflect the functionality it validates and grouped under its respective state.

    2.6.1 Charging State

ID | Test Name | Status | Date | Notes
CH-001 | Wireless Charging Alignment | Completed | 12/2/2024 | Verify proper alignment between the Qi transmitter and receiver.
CH-002 | Voltage Measurement During Charging | Completed | 12/2/2024 | Test voltage stability of the Qi receiver during charging.
CH-003 | Current Measurement for Qi Receiver | Completed | 12/2/2024 | Validate the maximum current handling of the Qi receiver.
CH-004 | Charging Under Full Load on PowerBoost | Completed | 12/2/2024 | Test charging behavior with a full load on the PowerBoost.
CH-005 | Charging Under Reduced Load on PowerBoost | Completed | 12/2/2024 | Test charging functionality with a reduced load on the PowerBoost.
CH-006 | LED Feedback: Low Battery (< 30%) | Pending | TBD | Validate flashing red LED when charging battery below 30%.
CH-007 | LED Feedback: Medium Battery (30%-50%) | Pending | TBD | Validate flashing yellow LED when charging battery between 30%-50%.
CH-008 | LED Feedback: High Battery (> 50%) | Pending | TBD | Validate flashing green LED when charging battery above 50%.
CH-009 | LED Feedback: Charging Complete | Pending | TBD | Verify solid blue LED when battery is fully charged (4.2V).
CH-010 | Overheat Alert During Charging | Pending | TBD | Test flashing orange LED when system temperature exceeds safe limits.

    2.6.2 Normal Operation State

ID | Test Name | Status | Date | Notes
OP-001 | Battery Monitoring: Green Level (> 50%) | Completed | 12/2/2024 | Test solid green LED during normal operation with battery > 50%.
OP-002 | Battery Monitoring: Yellow Level (30%-50%) | Pending | TBD | Test solid yellow LED during normal operation with battery between 30%-50%.
OP-003 | Battery Monitoring: Red Level (< 30%) | Pending | TBD | Test solid red LED during normal operation with battery < 30%.
OP-004 | Critically Low Battery (< 10%) Condition | Pending | TBD | Validate flashing red LED and system shutdown at critically low battery.
OP-005 | Battery Voltage Monitoring via Arduino | Completed | TBD | Monitor real-time battery voltage through Arduino serial output.
OP-006 | Temperature Monitoring During Operation | Pending | TBD | Verify temperature readings during normal and edge conditions.

# 2 Test Schedule

Table 1: Test Schedule

Document Event | Date
Test Plan released | 12/5/2024
Testing completed with results

# 3 Test Cases

The purpose of this section is to explain the nature and extent of each test and explain how the tests will evaluate system function or performance. This section also documents test input, specific test procedures, and outcomes.

## 4.1 CH-001

Objective: Verify the correct alignment between the Qi transmitter on the charging station and the Qi receiver on the rover.

Notes: This test ensures proper alignment for efficient wireless charging and tests the system's behavior in cases of misalignment. Estimated duration: 10 minutes. Resources required: charging station, rover, alignment markers, and LED feedback observation.

Test No.: CH-001 | | | | Current Status: Completed

Test title: Correct Alignment Between Qi Transmitter and Receiver

Testing approach: Test the alignment process to ensure the Qi transmitter and receiver align properly for charging. Verify feedback using LEDs and actual power transfer. |
STEP 1 | OPERATOR ACTION Place the rover on the charging station in the correct alignment position. | PURPOSE Test proper alignment for charging. | | | EXEPCTED RESULTS LED on the Transmitter lights up blue, indicating successful alignment. | COMMENTS Ensure alignment markers are visible to aid positioning.
2 | Shift the rover slightly off-center 8 mm and observe behavior. | Test system response to misalignment. | | | Charging stops, and the LED indicates an error RED. | Misalignment tolerance should be within 5 mm.
3 | Return the rover to the correct position and observe behavior. | Verify re-alignment restores charging. | | | Charging resumes, and the LED indicates proper alignment blue. | Ensure smooth transition from misalignment to aligned state.

Concluding Remarks: The alignment between the Qi transmitter and receiver is vital to ensure reliable charging. Misalignment can result in incomplete or failed power transfer, which should be minimized with proper alignment markers and system feedback mechanisms.
Testing Team: Turki Alturki, Belal Abed and Mohammed Alasmari | | | Date Completed: 12/2/2024

## 4.2 CH-002

#### Objective:

Measure the voltage output from the Qi receiver during charging to ensure it remains stable and within acceptable limits. Test how incorrect alignment affects voltage stability.

#### Notes:

This test ensures the Qi receiver outputs a stable voltage to the battery management system (BMS) and evaluates the impact of slight misalignment (within 5 mm tolerance). Voltage stability is critical for reliable charging.

Test No.: CH-002 | | | | Current Status: Completed

Test title: Voltage Measurement at Qi Receiver

Testing approach: Place the rover on the charging station, check the LED indication for alignment and charging, use a multimeter to measure the voltage output of the Qi receiver, and verify the effects of slight misalignment on voltage stability.
STEP 1 | OPERATOR ACTION Place the rover on the charging station. | PURPOSE Ensure the system initiates charging. | | | EXEPCTED RESULTS LED on the Transmitter lights up blue, indicating successful alignment. | COMMENTS Confirm proper alignment and system activation.
2 | Connect a multimeter to the output terminals of the Qi receiver circuit. | Measure voltage output during charging. | | | Voltage output is stable at 5V ± 0.1V. | Ensure no fluctuations or drops occur.
3 | Slightly misalign the rover within 5 mm tolerance and measure voltage. | Test the effect of slight misalignment on charging voltage. | | | . Voltage output is lower but charging still occurs < 5V | There will be a voltage drop due to misalligmnet

Concluding Remarks: Voltage stability is critical for proper charging. Misalignment within tolerance allows charging but results in reduced voltage output, potentially slowing the process. Severe misalignment halts charging altogether
Testing Team: Turki Alturki, Belal Abed and Mohammed Alasmari | | | Date Completed: 12/2/2024

## 4.3 CH-003

Objective:

Test the maximum current that the Qi receiver can provide using an electronic load. Confirm that the receiver operates safely within its limits and identify the actual maximum current capability.

Notes:

The Qi receiver is rated to provide a maximum current of 500 mA. This test uses an electronic load to gradually increase the current draw and measure the point at which the receiver reaches its limit. After testing, it was found that the receiver can provide up to 600 mA, slightly exceeding the expected value.

Test No.: CH-003 | | | | Current Status: Completed

Test title: Measure the current delivered to the receiver

Testing approach: Place the rover on the charging station, verify alignment and charging initiation, and use an electronic load to incrementally test the current output of the Qi receiver. Record the maximum stable current.
STEP 1 | OPERATOR ACTION Place the rover on the charging station. | PURPOSE Ensure the system initiates charging. | | | EXEPCTED RESULTS LED on the Transmitter lights up blue, indicating successful alignment. | COMMENTS Confirm proper alignment and system activation.
2 | Connect an electronic load to the Qi receiver's output terminals. | Simulate and control the current draw. | | | The electronic load is connected and ready for testing. | Ensure all connections are secure.
3 | Gradually increase the current draw using the electronic load. | Identify the receiver’s current limit. | | | The receiver provides stable current up to 500 mA. | Ensure no sudden voltage drops during the test.
4 | Observe behavior at 500 mA and higher current draws. | Test the receiver’s response to overload. | | | At > 600 mA, the receiver stops providing stable current, and charging may terminate. | The LED light on the transmitter lights up Red indicating an error

Concluding Remarks: The Qi receiver exceeded its expected 500 mA limit and safely delivered up to 600 mA. Current stability beyond 500 mA indicates a robust design, but prolonged use at this level may lead to potential thermal or hardware issues
Testing Team: Turki Alturki, Belal Abed and Mohammed Alasmari | | | Date Completed: 12/2/2024

## 4.4 CH-004

Objective:

Verify the system's behavior when charging the battery with a full load on the PowerBoost.

Notes:

This test evaluates the impact of a full load on the PowerBoost during charging. It checks whether the Qi receiver can handle the increased current demand and identifies the point of failure when the load exceeds its capacity.

Test No.: CH-004 | | | | Current Status: Completed

Test title: Charging System With Full Load on the PowerBoost

Testing approach:
Test the system's response when the PowerBoost is under full load during charging. Observe the transmitter LED and charging status of the battery.
STEP 1 | OPERATOR ACTION Connect the full load to the PowerBoost and ensure the system runs on battery. | PURPOSE Simulate a fully loaded system under battery operation. | | | EXEPCTED RESULTS System operates normally, with current draw as expected for full load. | COMMENTS Ensure stable operation with the load.
2 | Place the rover on the charging station and ensure alignment. | Attempt to start charging under full load. | | | Transmitter LED flashes red, and PowerBoost LED flashing yellow indicating charging failure. | Verify the system response to overcurrent conditions.
3 | Observe the battery charging status. | Verify the system's inability to charge under full load. | | | . Battery does not charge when the PowerBoost is under full load. | Confirm that the current exceeds the Qi receiver’s capacity.

Concluding Remarks: The system fails to charge the battery with a full load on the PowerBoost because the current demand exceeds the Qi receiver’s 500 mA limit
Testing Team: Turki Alturki, Belal Abed and Mohammed Alasmari | | | Date Completed: 12/2/2024

## 4.5 CH-005

Objective:

Verify the system's behavior when charging the battery with a lower load on the PowerBoost by unplugging the Pixy camera.

Notes:

This test evaluates the system's ability to charge the battery when the PowerBoost has a reduced load. Unplugging the Pixy camera decreases the current draw by 140 mA, allowing the Qi receiver to handle the current demand within its 500 mA specification.

Test No.: CH-005 | | | | Current Status: Completed

Test title: Charging System Without Load on the PowerBoost

Testing approach: Charging System With Lower Load on the PowerBoost
STEP 1 | OPERATOR ACTION Unplug the Pixy camera from the PowerBoost to reduce the load. | PURPOSE Simulate a reduced load condition under battery operation. | | | EXEPCTED RESULTS System operates normally, with current draw reduced by approximately 140 mA. | COMMENTS Verify stable operation with reduced load.
2 | Place the rover on the charging station and ensure alignment. | Attempt to start charging with the reduced load. | | | Transmitter LED solid blue, and PowerBoost LED solid yellow indicating normal charging. | Confirm proper operation of the charging system.
3 | Measure the total current drawn by the Qi receiver during charging. | Verify that the current is within the Qi receiver’s capacity. | | | Total current is 600 mA: 300 mA for battery charging and 300 mA for powering the PowerBoost and remaining load. | Ensure current measurements are accurate and stable.
4 | Observe the battery charging status. | Verify successful charging under reduced load conditions. | | | Battery charges steadily without interruptions. | Confirm the current allocation between charging and powering the system.

Concluding Remarks: When the Pixy camera is unplugged, reducing the PowerBoost load, the Qi receiver draws a total of 600 mA, of which 300 mA is used to charge the battery, and 300 mA powers the PowerBoost and remaining load. This configuration allows the system to charge successfully without exceeding the Qi receiver’s capacity. This test highlights the need for load management or upgrading the transmitter and receiver to handle higher current demands.
Testing Team: Turki Alturki, Belal Abed and Mohammed Alasmari | | | Date Completed: 12/2/2024

## 4.6 CH-006

Objective:

Verify that the ChargingLowBatteryLED (Red, Flashing) correctly indicates charging in progress when the battery level is below 30% (voltage < 3.5V).

Notes:

This test ensures that the LED flashes red when the battery voltage is below 3.5V (30%) during charging.

Test No.: CH-006 | | | | Current Status: Pending

Test title: ChargingBelow30PercentLED Behavior

Testing approach: Simulate a battery voltage below 3.5V, initiate charging, and observe the LED behavior.
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

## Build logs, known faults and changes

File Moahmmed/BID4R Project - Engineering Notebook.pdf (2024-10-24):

BID4R Project - Engineering Notebook

Project Contributor: Mohammed Alasmari

September 23, 2024: Initial Meeting with the Customer

- Objective: Understand project scope and gather requirements.
- Details: Attended an initial meeting with the customer to discuss the BID4R project's scope. Key areas of focus included the development of a distributed power management system, wiring design, and component integration. The customer emphasized the importance of battery management, cooling during charging, and ensuring safe, efficient integration of components. We also clarified that autonomous docking for charging was out of scope, meaning the operator would manually place the robot in the charging station when the battery is low.

September 26, 2024: Received Components List
- Objective: Begin component review and analysis.
- Details: The team received an Excel file that included a list of all components we would use in the BID4R project. Each component's link was provided, allowing us to access their specifications directly. This enabled us to assess their suitability based on factors such as voltage, current requirements, and safety features, ensuring they aligned with the project’s technical needs.

September 28, 2024: Team Meeting to Draft the Proposal
- Objective: Collaborate with the team to structure the project proposal and backlog.
- Details: Participated in a team meeting where we began drafting the project proposal and outlining the backlog. My contributions involved defining key milestones, such as power management and wiring integration, and ensuring we had a clear understanding of each task's dependencies. The backlog was populated with high-level tasks that we planned to break down into more detailed steps as the project progressed.

September 29, 2024: Submission of Project Proposal
- Objective: Finalize and submit the project proposal.
- Details: Met again with the team to submit the project proposal. My assigned task was to research existing and alternative components to ensure the project used suitable parts that meet the project goals.

### 5. October 1, 2024: Stakeholder Meeting

- Objective: Officially receive the robot for development work.
- Details: Met with stakeholders and received the physical robot, which marked the start of the component integration process.

October 2, 2024: Component Specification and Suitability Check

- Objective: Begin detailed analysis of component specifications and evaluate their suitability for the BID4R system.
- Details:
1. Component Specification Review:
a. I began by carefully reviewing the technical specifications of each
component in the system, including power requirements, dimensions, and connectivity. The focus was on ensuring that all components could function within the power limits provided by the system's power supply, and that each part could integrate smoothly with others. This analysis was compiled into a Component Specification Review file, which included detailed documentation on the specifications of components like the PowerBoost 1000C, Arduino Nano 33 IoT, sensors, and the Qi charging modules.
b. The review covered components such as:
i. PowerBoost 1000C: Its input and output voltage (3.7V from the LiPo battery, outputting 5V) and its continuous current capacity of 1A were verified. The goal was to ensure it could power all sensors and the Arduino without risk of overloading.
ii. Motors: Checked voltage range (3-6V), current draw, and the potential for stall currents that could exceed safe operating limits. iii. Batteries and Charging Components: The compatibility of the 3.7V LiPo battery with other components, especially in terms of voltage and capacity, was analyzed.
2. Suitability Check of PowerBoost 1000C and Sensors/APA106 LEDs:
a. I examined the PowerBoost 1000C and its ability to power the sensors and LEDs within the system. The PowerBoost provides a stable 5V output, which is necessary to power components such as the Pixy2 Smart Vision Sensor (5V, 140mA) and the VCNL4010 Proximity/Light Sensor (3.3-5V, 8mA).

Additionally, two APA106 Addressable RGB LEDs were evaluated, each drawing 20mA.
b. The total current draw from these components was calculated to be around 188mA, well within the PowerBoost’s continuous output capacity of 1A. This provided ample headroom for other components, like the Arduino Nano 33 IoT, to operate safely. I confirmed that the PowerBoost 1000C was suitable for powering these components without the risk of overload, and this analysis was documented in the Suitability Check for Existing Components file.
3. Suitability Check of Arduino Nano 33 IoT and Sensors:
a. I evaluated the Arduino Nano 33 IoT, which serves as the main processing unit in the system, for compatibility with connected sensors such as the Pixy2 Smart Vision Sensor and the VCNL4010 Proximity/Light Sensor. The Arduino operates at 3.3V logic, which matches the I2C logic level of both sensors, ensuring no need for additional logic level conversion.
b. The Pixy2 Smart Vision Sensor requires 5V power but communicates using 3.3V logic, making it fully compatible with the Arduino. The VCNL4010 Proximity Sensor can operate between 3.3V and 5V, further aligning with the Arduino Nano 33 IoT. I confirmed that both sensors could be powered directly by the Arduino and operate within their expected parameters. This verification was summarized in the Suitability Check for Existing Components file.
4. Suitability Check of Motors, Motor Controller, and Battery:
a. For the DC Motors in the Mini 3-Layer Round Robot Chassis Kit, I reviewed their voltage requirements (3-6V) and current draw (200-400mA under normal operation, 1.5A during stall conditions). I determined that the 3.7V LiPo battery would provide adequate power, though the motors might operate with slightly reduced performance compared to a 6V supply. However, this was deemed acceptable for the project's needs.
b. I also evaluated the Adafruit DRV8833 Motor Driver, which controls the motors and has a continuous current limit of 1.2A per channel, with a peak limit of 2A. Given that the motors can draw up to 1.5A during a stall, I recommended installing 1.5A fuses in series with the motors to protect the motor controller from potential damage caused by overcurrent.
c. The 3.7V, 3000mAh LiPo battery was analyzed for capacity and safety. The battery's capacity was deemed sufficient to power the entire system for an extended period. However, I identified the need for a Battery Management System (BMS) to prevent overcharging, over-discharging, and short circuits, thus ensuring the battery's long-term health and safe operation. These protective measures were critical to ensuring the safe functioning of the system. The findings were summarized in the Suitability Check for Existing Components file.

October 3, 2024: Identifying Additional Components and Initial Power Calculations
- Objective: Identify necessary additional components and perform initial power calculations for the robot’s operation.
- Details:
1. Identifying Additional Components:
After reviewing the existing component specifications and suitability, I listed the Battery Management System (BMS) and fuses as additional components required for the project. The BMS is essential for managing the LiPo battery, ensuring protection against overcharging, over-discharging, and short circuits, which are critical to battery longevity and safety. The fuses, particularly the 1.5A slow-blow fuses, are necessary to protect the motor controller from overcurrent situations that could occur during motor stalls.

October 4, 2024: Initial Power Calculations
- Objective: Calculate how long the robot would operate under both normal and stall conditions.
- Details:

I worked with Belal to begin the initial calculations to determine how long the robot would operate under both normal conditions and during stall conditions. We used
the formula P=V×I to calculate the power consumption for each component.

Motors: Under normal conditions, each motor draws 0.3A, resulting in a total power consumption of 2.22W for both motors. During stall conditions, the current draw increases to 1.5A per motor, resulting in 11.1W for both motors.

Other Components: We calculated the power consumption of the Pixy2 Camera, VCNL4010 Proximity Sensor, Arduino Nano 33 IoT, and APA600 LEDs, which are powered by the PowerBoost 1000C. The total power consumption from these components was 1.72W.

Total Power Consumption: For normal operation, the total system power consumption was calculated to be 3.94W, while during stall conditions, it increased to 12.82W.
Battery Runtime: We used the energy stored in the LiPo battery (11.1Wh) to estimate the runtime. For normal operation, the robot can run for approximately 2.82 hours (169 minutes). In stall conditions, the runtime drops to about 0.87 hours (52 minutes).

These calculations were essential for estimating the robot’s battery life and ensuring the power system could handle peak loads without overloading.

We also applied a more detailed formula to calculate the operating time based on different load conditions:

This formula allows us to estimate the total operating time based on how frequently the robot operates under normal or heavy (stall) conditions. For example, if the robot operates under heavy load for 10% of the time and normal load for 90%, we can calculate how long the battery will last under these conditions. This formula is crucial for understanding the robot’s overall runtime in mixed operating scenarios and helps in optimizing power management.

October 17, 2024: Stakeholder Meeting to Review Charging Station and Additional Components
- Objective: Review the charging station design and additional components list with stakeholders.
- Details:

During a meeting with the stakeholders, we reviewed the charging station design and the additional components list that I provided on October 15. The key discussions included the need for a Battery Management System (BMS) and fuses for the BID4R project.

- BMS Approval: The stakeholders agreed to provide the BMS for the project, acknowledging its importance in ensuring safe operation of the LiPo battery, particularly in managing overcharging, over-discharging, and short circuits.

- Fuse Discussion: While the stakeholders accepted the BMS, there was some uncertainty regarding the necessity of the 1.5A fuses I had recommended. They were unsure if the fuses were needed to protect the motor driver during stall conditions.
October 18, 2024: Finalization of Power Calculations
- Objective: Finalize power calculations after adding resistors for new components.
- Details:

I finalized the power calculations after we added two resistors to the system—one for the DS18B20 Temperature Sensor and one for the Adafruit Power Relay FeatherWing.
These updates were necessary to ensure proper operation and voltage regulation for the new components.
- Updated Power Consumption:
- The DS18B20 Temperature Sensor draws 0.0075W.
- The Adafruit Power Relay FeatherWing draws 0.1W.
- Total Power Consumption: With these additions, the total power consumption during normal operation was recalculated to be 4.17W, and during stall conditions, it increased to 13.05W.
- Battery Runtime: After the adjustments, the estimated runtime for the robot was about 2.66 hours under normal conditions and 0.85 hours during stall conditions.
- Current Draw: The total current draw from the PowerBoost 1000C was calculated to ensure it remained within the 1A limit, and the system was confirmed to be well within this limit at 0.39A.
- This final calculation provided a more accurate estimate of the robot’s performance under various conditions and ensured that the power system could handle the additional components efficiently.

October 18, 2024: provide feedback of Wiring Diagram
- Objective: Provide feedback on the wiring diagram and ensure correct component connections.
- Details:

Turki started working on the wiring diagram in fritzing for the BID4R project. I provided feedback on how the components should be connected. Key points included:

- Resistor Placement: I highlighted that we needed two resistors for monitoring the battery and one additional resistor between the Arduino and the LED to ensure proper voltage and current regulation.
- Sensor Power Source: I also checked to ensure that all sensors were being powered by the PowerBoost, and I confirmed that this was done correctly. The sensors were successfully powered by the PowerBoost, ensuring the system would function as intended.

The wiring diagram was progressing well, and the connections appeared to be set up effectively.

October 24, 2024: Stakeholder Meeting to Print Charging Station and Review Calculations

- Objective: Print the charging station and discuss the power calculations.
- Details:

During a meeting with the stakeholders, we printed the charging station and reviewed the final power calculations. I provided a detailed explanation of the stall condition, clarifying its impact on the robot’s operation and why the motor’s current spikes during these situations.

The stakeholders mentioned that they would review the calculations once more and provide additional feedback. However, they decided not to order the fuses, expressing that they did not believe the system would need them, as they were confident that overcurrent situations during stall conditions were unlikely to occur.

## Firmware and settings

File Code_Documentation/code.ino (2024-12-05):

#include <Wire.h>
#include <Adafruit_NeoPixel.h>
#include <OneWire.h>
#include <DallasTemperature.h>
#include <Pixy2.h>
#include <SPI.h>


// Pin Definitions
#define PIXY_RX_PIN 0            // Pixy2 Camera RX for serial communication
#define PIXY_TX_PIN 1            // Pixy2 Camera TX for serial communication
#define MOTOR_AIN1 2             // Motor 1 PWM speed control
#define MOTOR_AIN2 3             // Motor 1 direction control
#define TEMP_PIN 12               // DS18B20 Temperature Sensor (Data pin)
#define MOTOR_BIN1 5             // Motor 2 PWM speed control
#define MOTOR_BIN2 6             // Motor 2 direction control
#define POWERBOOST_ENABLE 7      // PowerBoost ENABLE through transistor 2A2222A
#define LED_PIN 8                // APA106 LED for LED strip
#define RELAY_PIN 9              // Control Power Relay
#define FEEDBACK_LED 10          // LED for robot feedback
#define BATTERY_LBO 11           // this pin is not correct it is used for alerting the operator that the battery is less than 3.2v
#define MOTORS_SLEEP 4         // Motors Sleep/12
#define BATTERY_PIN A0           // Voltage Divider for battery level monitoring
#define PROXIMITY_SDA A4         // Proximity Sensor SDA (I2C communication)
#define PROXIMITY_SCL A5         // Proximity Sensor SCL (I2C communication)
#define CHARGING_PIN 13

// Battery and Temperature Thresholds
const float R1 = 3300.0;          // Resistor R1 (3.3kΩ)
const float R2 = 10000.0;         // Resistor R2 (10kΩ)
const float MAX_VOLTAGE = 4.2;    // Maximum allowable battery voltage
const float HIGH_TEMP_THRESHOLD = 45; // High temperature threshold (Celsius)
const float LOW_TEMP_THRESHOLD = 35;  // Cool-down temperature threshold (Celsius)
const float batteryMaxVoltage = 4.2;  // Maximum battery voltage
const float voltage50Percent = 3.7;   // Voltage at 50% charge
const float voltage30Percent = 3.5;   // Voltage at 30% charge
const float voltage10Percent = 3.3;   // Voltage at 10% charge

const int BATTERY_READINGS = 10;  // Number of readings for averaging
float batteryReadings[BATTERY_READINGS] = {0}; // Buffer for voltage readings
int readIndex = 0;                // Index for rolling average buffer

// LED Behavior Parameters
#define COLOR_GREEN strip.Color(0, 255, 0)
#define COLOR_YELLOW strip.Color(255, 255, 0)
#define COLOR_RED strip.Color(255, 0, 0)
#define COLOR_BROWN strip.Color(139, 69, 19)

// NeoPixel Strip Initialization
Adafruit_NeoPixel strip = Adafruit_NeoPixel(1, LED_PIN, NEO_GRB + NEO_KHZ800);
// DS18B20 Sensor Initialization
OneWire oneWire(TEMP_PIN);
DallasTemperature sensors(&oneWire);
Pixy2 pixy;

void updateLEDStatus(float batteryVoltage, bool charging, bool temperatureHigh = false);


void setup()
{
  Serial.begin(9600);
  

  strip.begin();                          // Initialize LED strip library
  strip.clear();                          // Clear the LED strip
  strip.show();                           // Update the LED strip
  Wire.begin();
  sensors.begin();
  pixy.init();
  Serial.println("Pixy2 Initialized");

  pinMode(MOTOR_AIN1, OUTPUT);   // PWM speed control
  pinMode(MOTOR_AIN2, OUTPUT);   // Direction control
  pinMode(MOTOR_BIN1, OUTPUT);   // PWM speed control
  pinMode(MOTOR_BIN2, OUTPUT);   // Direction control
  pinMode(TEMP_PIN, INPUT);      // DS18B20 data pin
  pinMode(POWERBOOST_ENABLE, OUTPUT);  // Enable PowerBoost via transistor
  pinMode(LED_PIN, OUTPUT);      // Data pin for APA106 LED strip
  pinMode(RELAY_PIN, OUTPUT);    // Control relay for charging
  pinMode(FEEDBACK_LED, OUTPUT); // General feedback LED
  pinMode(BATTERY_LBO, INPUT);   // PowerBoost battery monitoring (digital input)
  pinMode(MOTORS_SLEEP, OUTPUT); // Sleep pin to control motors' power state

  digitalWrite(POWERBOOST_ENABLE, HIGH);  // Turn on PowerBoost
  digitalWrite(MOTORS_SLEEP, HIGH);        // Put motors in sleep mode initially
  digitalWrite(RELAY_PIN, LOW);           // Ensure relay is off (charging inactive)


  Serial.print("Starting...\n");
  
}

// Main Loop
void loop() {
    // Measure battery voltage and check if temperature is high
    float battery_voltage = monitorBattery();
    float temperature = monitorTemperature();
    bool temperatureHigh = temperature >= HIGH_TEMP_THRESHOLD;

    // Logic to handle different states
    if (isCharging()) {
        // If charging, manage the charging process
        stopFunctions();
        chargingManagement(battery_voltage, temperature);
    } 
    else if (battery_voltage <= voltage10Percent) {
        // If battery voltage is critically low
        Serial.println("Battery voltage critically low! Stopping all functions.");
        stopFunctions(); // Stop all non-essential components
        updateLEDStatus(battery_voltage, false, temperatureHigh); // Update LED for critical state
    } 
    else {
        // Normal operation
        updateLEDStatus(battery_voltage, false, temperatureHigh); // Update LED in normal operation mode
        enableFunctions();

        // Perform robot operations
        // Move Forward
        analogWrite(MOTOR_AIN1, 200);
        analogWrite(MOTOR_AIN2, 0);
        analogWrite(MOTOR_BIN1, 200);
        analogWrite(MOTOR_BIN2, 0);
        delay(1000);

        // Turn right
        analogWrite(MOTOR_AIN1, 0);
        analogWrite(MOTOR_AIN2, 200);
        analogWrite(MOTOR_BIN1, 200);
        analogWrite(MOTOR_BIN2, 0);
        delay(1000);

        // Move backward
        analogWrite(MOTOR_AIN1, 0);
        analogWrite(MOTOR_AIN2, 200);
        analogWrite(MOTOR_BIN1, 0);
        analogWrite(MOTOR_BIN2, 200);
        delay(1000);

        // Turn left
        analogWrite(MOTOR_AIN1, 200);
        analogWrite(MOTOR_AIN2, 0);
        analogWrite(MOTOR_BIN1, 0);
        analogWrite(MOTOR_BIN2, 200);
        delay(1000);

        // Pixy2 Block Detection
        int i;
        pixy.ccc.getBlocks();
        if (pixy.ccc.numBlocks) {
            Serial.print("Detected ");
            Serial.println(pixy.ccc.numBlocks);
            for (i = 0; i < pixy.ccc.numBlocks; i++) {
                Serial.print("  block ");
                Serial.print(i);
                Serial.print(": ");
                pixy.ccc.blocks[i].print();
            }
        }
    }

    // Delay before next loop iteration
    delay(1000);
}





// Function to monitor battery voltage with smoothing
float monitorBattery() {
    int sensorValue = analogRead(BATTERY_PIN);
    float voltage = sensorValue * (3.3 / 1023.0); // ADC to voltage conversion
    float batteryVoltage = voltage * (R1 + R2) / R2; // Voltage divider formula

    // Update rolling average buffer
    batteryReadings[readIndex] = batteryVoltage;
    readIndex = (readIndex + 1) % BATTERY_READINGS;

    // Calculate average voltage
    float averageVoltage = 0;
    for (int i = 0; i < BATTERY_READINGS; i++) {
        averageVoltage += batteryReadings[i];
    }
    averageVoltage /= BATTERY_READINGS;

    Serial.print("Battery Voltage: ");
    Serial.println(averageVoltage);
    return averageVoltage;
}

// Function to monitor temperature using the DS18B20 sensor
float monitorTemperature() {
    sensors.requestTemperatures(); 
    float temperature = sensors.getTempCByIndex(0);
    Serial.print("Temperature: ");
    Serial.println(temperature);
    return temperature;
}

// Function to update LED status based on battery voltage and robot state
void updateLEDStatus(float batteryVoltage, bool charging, bool temperatureHigh) {
    static unsigned long previousMillis = 0;
    const unsigned long interval = 500; // Flash interval in milliseconds
    unsigned long currentMillis = millis();

    // Charging Mode LED Behavior
    if (charging) {
        if (temperatureHigh) {
            // Flash orange if temperature is too high
            if (currentMillis - previousMillis >= interval) {
                previousMillis = currentMillis;
                static bool ledOn = false;
                ledOn = !ledOn;
                if (ledOn) {
                    strip.setPixelColor(0, strip.Color(255, 165, 0));  // Flash Orange for high temperature
                } else {
                    strip.clear();
                }
                strip.show();
            }
        } else if (batteryVoltage >= batteryMaxVoltage) {
            // Solid blue when fully charged
            strip.setPixelColor(0, strip.Color(0, 0, 255));  // Solid Blue for fully charged
            strip.show();
        } else {
            // Flash based on battery voltage level
            if (currentMillis - previousMillis >= interval) {
                previousMillis = currentMillis;
                static bool ledOn = false;
                ledOn = !ledOn;

                if (ledOn) {
                    if (batteryVoltage >= voltage50Percent) {
                        strip.setPixelColor(0, COLOR_GREEN);  // Flash Green above 50%
                    } else if (batteryVoltage >= voltage30Percent) {
                        strip.setPixelColor(0, COLOR_YELLOW);  // Flash Yellow between 30%-50%
                    } else {
                        strip.setPixelColor(0, COLOR_RED);  // Flash Red below 30%
                    }
                } else {
                    strip.clear();
                }
                strip.show();
            }
        }
    }
    // Normal Operation LED Behavior
    else {
        if (batteryVoltage >= voltage50Percent) {
            strip.setPixelColor(0, COLOR_GREEN);  // Solid Green above 50%
        } else if (batteryVoltage >= voltage30Percent) {
            strip.setPixelColor(0, COLOR_YELLOW);  // Solid Yellow between 30%-50%
        } else if (batteryVoltage <= voltage30Percent) {
            strip.setPixelColor(0, COLOR_RED);  // Solid Red for critical charge
        }
        strip.show();
    }
}

// Function to check if the robot is charging
bool isCharging() {
    int lboStatus = digitalRead(CHARGING_PIN);
    return lboStatus == HIGH;
}
// this pin i snot correct it is used for alerting the operator that the battery is less than 3.2v
// Charging Management Function with Pre-Measured Values
void chargingManagement(float battery_voltage, float temperature) {
    while (isCharging()) {  // Loop as long as the robot is in charging mode
        static unsigned long previousMillis = 0;
        const unsigned long interval = 500;  // Check conditions every 500ms
        unsigned long currentMillis = millis();

        // Perform condition checks only at specified intervals
        if (currentMillis - previousMillis >= interval) {
            previousMillis = currentMillis;

            battery_voltage = monitorBattery();
            temperature = monitorTemperature();

            // Check if both conditions for safe charging are met
            if (battery_voltage < MAX_VOLTAGE && temperature < HIGH_TEMP_THRESHOLD) {
                Serial.println("Both conditions met: Starting charging...");
                digitalWrite(RELAY_PIN,LOW);  // Start charging
                updateLEDStatus(battery_voltage, true, false);  // Update LED to indicate charging
            }
            // If combined conditions are not met, check individual conditions
            else {
                if (battery_voltage >= MAX_VOLTAGE) {
                    Serial.println("Battery voltage is too high: Stopping charging...");
                    digitalWrite(RELAY_PIN, HIGH);  // Stop charging
                    updateLEDStatus(battery_voltage, true, false);  // Update LED to show high voltage
                }

                if (temperature >= HIGH_TEMP_THRESHOLD) {
                    Serial.println("Temperature is too high: Stopping charging...");
                    digitalWrite(RELAY_PIN, HIGH);  // Stop charging
                    updateLEDStatus(battery_voltage, true, true);  // Update LED to show high temperature
                    Serial.println("Waiting for temperature to cool down...");

                    // Wait until temperature falls below the low threshold
                    while (monitorTemperature() > LOW_TEMP_THRESHOLD) {
                        updateLEDStatus(battery_voltage, false, true);  // Continuously update LED
                        delay(500);  // Optional: slow down checks
                    }

                    Serial.println("Temperature cooled down: Restarting checks...");
                    continue;  // Restart the loop to recheck all conditions
                }
            }
        }
    }
}



// Function to stop non-essential components
void stopFunctions() {
    Serial.println("Stopping non-essential components...");
    digitalWrite(POWERBOOST_ENABLE, LOW); // Disable PowerBoost
    digitalWrite(MOTORS_SLEEP, LOW);      // Put motors to sleep
}

// Function to enable non-essential components
void enableFunctions() {
    Serial.println("Enabling non-essential components...");
    digitalWrite(POWERBOOST_ENABLE, HIGH); // Enable PowerBoost
    digitalWrite(MOTORS_SLEEP, HIGH);      // Wake up motors
}
